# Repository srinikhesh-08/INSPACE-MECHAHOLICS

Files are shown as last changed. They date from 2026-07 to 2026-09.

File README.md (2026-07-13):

# INSPACE-MECHAHOLICS
## This is where all the hardware and software documentation for the competition will be saved

## MECHANICAL SUBSYSTEM

The Mechanical Subsystem provides the structural framework, component integration, and recovery system for the CanSat. The design follows the CAN7USAT dimensional constraints (15 cm × 40 cm) while maintaining low mass and high structural integrity during launch, deployment, descent, and landing.

The structure consists of a lightweight PETG outer casing, a six-pillar aluminium frame, and internal mounting plates for electronics, batteries, and sensors. The six-pillar configuration was selected over conventional three- and four-pillar designs due to its improved stiffness, vibration resistance, and torsional rigidity.

Recovery is achieved using a dual-stage parachute system. A drogue parachute is deployed at apogee to stabilize the vehicle, followed by the main parachute at approximately 600 m AGL to achieve a controlled landing. Deployment is servo-actuated using a spring-loaded release mechanism. A commercial off-the-shelf (COTS) altimeter provides redundant deployment capability in the event of primary sensor failure.

## ELECTRICAL POWER SYSTEM

The Electrical Power Subsystem (EPS) supplies regulated power to all avionics while ensuring reliable operation throughout the mission.

The system uses a 2S1P Samsung INR18650-30Q Li-ion battery pack (7.4 V, 3000 mAh), selected for its high current capability, competition compliance, and excellent energy density. Power is regulated through an MP1584 buck converter (7.4 V → 5 V) followed by a TPS73733 low-noise LDO regulator (5 V → 3.3 V), providing dedicated rails for digital logic and sensors.

Protection features include reverse-polarity protection, transient voltage suppression (TVS), fuse protection, battery voltage monitoring, and an externally accessible master power switch.

The average system power consumption is approximately 2.5 W, providing over 7 hours of safe operating time, significantly exceeding the competition's two-hour minimum requirement.

## SENSOR SUBSYSTEM
The Sensor Subsystem collects all mission-critical flight data required for navigation, telemetry, recovery, and post-flight analysis.

The primary altitude and temperature sensor is the BMP581, providing high-resolution pressure measurements and integrated temperature sensing. Vehicle orientation is determined using the BNO086 intelligent IMU, which performs onboard sensor fusion to provide stable quaternion-based attitude estimation while minimizing processor load.

Position and velocity are obtained using the NEO-M9N multi-constellation GNSS receiver, supporting GPS, GLONASS, Galileo, and BeiDou.

Sensor data is transmitted to the ground station through the SX1276 LoRa radio while simultaneously being stored locally on a microSD card for redundancy.

## COMMUNICATION AND DATA HANDLING

The Communication and Data Handling (CDH) subsystem manages onboard data acquisition, storage, telemetry transmission, and communication between all flight hardware.

The STM32F405 flight controller serves as the central processor, collecting data from sensors through I²C, SPI, and UART interfaces. Flight telemetry is transmitted using the SX1276 LoRa radio while identical datasets are simultaneously logged to onboard microSD storage to prevent data loss.

The subsystem maintains synchronized sensor acquisition, packet formation, telemetry scheduling, and storage throughout all flight phases. The communication architecture supports continuous monitoring of system health, mission parameters, and recovery status.

## FLIGHT SOFTWARE

The Flight Software (FSW) controls all mission operations through a finite state machine (FSM) running on FreeRTOS.

Mission execution progresses through seven primary states: Boot, Test Mode, Launch Pad, Ascent, Primary Descent, Secondary Descent, and Impact. Each state activates specific sensing, logging, telemetry, and recovery tasks appropriate for that phase of flight.

The software architecture is task-based, separating sensor acquisition, telemetry, data logging, communication, health monitoring, and state management into independent FreeRTOS tasks. This modular design improves reliability, simplifies debugging, and allows future subsystem expansion.

A dedicated TestAndSim framework enables complete mission simulation using synthetic sensor data, allowing firmware validation without flight hardware. Both unit testing and full mission integration testing are performed before deployment.

## GROUND CONTROL SYSTEM

The Ground Control System (GCS) provides real-time monitoring, visualization, and recording of flight telemetry received from the CanSat.

The desktop application is developed in Python using PyQt6 and PyQtGraph to display live telemetry, mission status, altitude, sensor measurements, and system health. Incoming LoRa packets are decoded, visualized, and simultaneously archived into timestamped CSV files for post-flight analysis.

The GCS also provides mission state indication, communication status, and recovery support, enabling operators to monitor the vehicle throughout the complete mission.

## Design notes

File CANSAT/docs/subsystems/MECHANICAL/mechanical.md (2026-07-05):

## Mechanical Subsystem

The Mechanical Subsystem is responsible for:

- Providing the structural framework of the CanSat
- Ensuring safe integration of all components
- Supporting the recovery system

Major Structural Components

1. Outer Casing
2. Structural Frame
3. Plates

### Structural Components
#### Outer Casing

Cylindrical structure conforming to CAN-7USAT dimensions (In our case it is 15x40 CM)
Protects internal components (electronics) from dust and moisture in air and also protects from Mechanical shocks during ascent and descent 
Design Requirements:
- Lightweight 
- Accessible 
- Ventilation 
CanSat outer casing should be light in weight so that it meets the mass budget but, should be strong enough and should have access to remove top and bottom for better integration and ventilation should be provided through vent holes so that sensors like pressure,temperatures exposed to outside air 

#### Materials for outer casing

- PETG
- PLA
- ABS
- Fiberglass
- Carbon fiber: By using 3D-printing we could go with PETG as better option because it is strong and light in weight compared to others

#### Structural frame 
    It is the skeleton of the cansat .It supports all components to maintain their position and protect from loads experienced during the launch,payload separation and landing.
    
#### Functions:
Components mounting 
Absorbs loads
Protection and alignment 

#### Frame Design

Number of Pillars: 6

A **hexapillar configuration** has been selected instead of 3-pillar or 4-pillar designs.

Reasons for Selection

- Higher structural strength
- Better vibration resistance
- Greater torsional rigidity

#### Materials

- 3D-printed PETG circular plates
- Aluminum pillars

Estimated Mass

- Structural frame mass: **200–250 g**

---

###  Structural Components

#### Plates

Plates serve as mounting surfaces for:

- Provides mounting surfaces for PCBs,sensors,batteries.
- Increase stiffness for CanSat 
- They are Manufactured from Lightweight material either aluminum or composites

 Other things such as fasteners and connectors are stainless steel screws ,etc..
 Safe integration of components in these structures provides nominal performance of components which meets the mission requirements such as recovery, telemetry,etc..

#### Recovery System
After separation from Launcher, CanSat needs it’s own recovery system to land safely without any damages . CanSat will have two descent control systems( Primary and Secondary) 
Recovery options:                                                           
- Parachutes 
- Rotors 
- Gliders 
- Streamers 
 The best options among them  are either parachutes or rotors, glider and streamers are not preferable due to mass and volume constraints 

#### Parachutes deploying mechanism :
Parachutes and spring system are well packed and prepared for launch, Once CanSat is deployed from the rocket, flight controller detect the condition and send command to servo to rotate and latch disengages so that spring push the top part of the CanSat and parachutes will be expelled into airflow and it inflates and continues controlled descent till landing

For **primary descent control** we use drogue parachutes will 
Engage at apogee while for secondary descent control system

We use main parachutes which will engage at 600m altitude 

#### Backup descent strategy:
All the conditions will updated to MCU by altitude sensor so, in recovery it plays a vital in engaging of parachutes at desired altitudes. In case, if any anomaly in sensor part then we activate COTS altimeter which is commercial altimeter, which will monitor the altitude independently and will guide the MCU to take further actions to recover the CanSat by deploying parachutes. 

##### COTS Preference Order:                        
1. Missile Works RRC3+
2. PerfectFlite StratoLoggerCF
3. Eggtimer Quark

---

### Parachutes: 
#### Aerodynamics of Parachutes:
The drag force is dependant upon 
1) the dynamic pressure created by moving air striking the parachute canopy (and which keeps the parachute inflated)
2) the diameter of the parachute, which determines the area over which the dynamic pressure acts 
3) the drag coefficient, Cd, of the parachute.
 Dynamic pressure is a function of velocity and air density, which in turn is dependent upon altitude and temperature.

####  Descent rate of parachutes
The vertical descent rate provided by parachute in stable descent rate is give by :



Wt = total weight of body and parachute 
S = canopy reference (surface) area   
r = air density 
To get the canopy area of parachutes :
To get descent velocity around 5m/s the relation between diameter and mass is given by:  
                                                Diameter = 0.9*(mass)^½  where mass is in kg  
                                  **Since our CanSat mass is around 1kg , required diameter is around 90cm for main chutes**

####  Calculations for descent velocity 
Mass m=1kg
Parachute diameter d=0.9m
Area A=πr² =0.64m² 
Drag coefficient Cd=0.8
Air density ρ=1.225 kg/m³ 
Using:
v=√ (2mg/ρCdA)  ≈  5.6 m/s
The terminal descent velocity is subjected to change based on air density at location of launch and weather conditions 

#### Parachute Design
Types of parachutes based on the shapes:
More common shapes are flat circular, conical, bi-conical, hemispherical, ellipsoidal, cross, annular, toroidal, ringslot, ringsail and ribbon- type 
1. Parasheet or flat circular                                          
2. Elliptical or ellipsoidal
3. Cruciform or cross

The parasheet is simplest to make, it is basically a single piece of fabric cut to a circular shape. Shroud lines are sewn onto the hemmed circumference.

####  Parachute design 




According to some research papers,
Circular form parachute is considered best of these        
1. It will give stable descent rate 
2. Prevent swinging(oscillations)
3. Open reliably 
Material: Ripston Nylon           

---

### Mass Budget

#### Electrical Components
 
| Component | Model | Est. Mass (g) |
|---|---|---:|
| Flight Computer | STM32F405 Flight Controller | 15 |
| Altimeter | BMP585 Breakout Module | 20 |
| IMU | BNO086 Breakout Module | 3 |
| GNSS | NEO-M9N Module + antenna | 22 |
| Telemetry Radio | SX1276 LoRa Module | 5 |
| Camera | M5StackCAM (OV2640) | 15 |
| Data Logger | MicroSD Module + Card | 4 |
| Buck Converter | MP1584 Module | 10 |
| LDO Regulator | TPS73733 Circuit | 1 |
| Wiring & Connectors | JSTs, headers, cables | 30 |
| PCB (custom avionics board) | Main electronics board | 30 |
| **Total (Electrical)** | | **155** |
 
#### Mechanical Components
 
| Component | Est. Mass (g) |
|---|---:|
| 2× Samsung INR18650-30Q | 100 |
| Primary Parachute | 25 |
| Secondary Parachute | 15 |
| Servo Mechanism | 30 |
| CanSat Structure (frame, fasteners, mounts) | 300 |
| Recovery Buzzer | 10 |
| Status LEDs | 2 |
| **Total (Mechanical)** | **482** |
 
#### Total Mass Budget
 
```
Total Mass = Electrical (155 g) + Mechanical (482 g) = 637 g
```

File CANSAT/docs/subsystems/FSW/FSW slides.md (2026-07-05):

# FSW Overview

- The finite state machine contains the above states:
    - BOOT
        - Hardware &software initialisation.Sensor buses, SDcard mount, previous state recovery, health diagnostics.
    - TEST_MODE
        - Live sensor validation, telemetry demo packets, SD write test, GCS link verification before launch.
    - LAUNCH_PAD
        - Pre-launch idle. 1 Hz telemetry begins. Gyro, baro & accel calibration on command. Launch detection armed.
    - ASCENT
        - All telemetry streaming.Continuous altitude, IMU, GNSS, voltage logging. Apogee detection via altitude trend.
    - PRIMARY_DESCENT
        - Post-ejection. Primary parachute deployed. Passive stabilisation. Descent rate target <20 m/s.
    - SECONDARY_DESCENT
        - Activated at 600 ± 10 m AGL. Secondary mechanism deployed.Gyroscopic stabilisation active. Target 1–3 m/s.
    - IMPACT
        - Low altitude + IMU deceleration spike. Audio beacon on. Final telemetry sent. SD card finalised.

- The FSW was divided into the following modules by functionality:
   
                          +------------------------------------------------------+
                          |                Communication Layer                   |
                          | GCS uplink/downlink • Packet serialization • Commands|
                          +--------------------------+---------------------------+
                                                     |
                                                     v
                          +------------------------------------------------------+
                          |                     FSW Core                         |
                          | State Machine • Watchdog • Task Scheduler • Commands |
                          +--------------------------+---------------------------+
                                                     |
                                                     v
                          +------------------------------------------------------+
                          |                    Data Layer                        |
                          | Sensor Fusion • Complementary Filter • AbstractState |
                          +--------------------------+---------------------------+
                                                     |
                           +-------------------------+-------------------------+
                           |                                                   |
                           v                                                   v
          +--------------------------------------+      +--------------------------------------+
          |      Hardware Controller Layer       |      |         TestAndSim Suite            |
          | IMU • Barometer • GNSS • LoRa • SD   |      | Drop-in Hardware Replacement        |
          | Hardware Drivers & Interfaces        |      | Simulated Sensors & Testing         |
          +--------------------------------------+      +--------------------------------------+

                        +----------------------------------------------+
                        |           Config Module (config.h)           |
                        | Shared configuration used by all layers      |
                        +----------------------------------------------+
```

---

- FSW TASKS (Scheduled by FreeRTOS)
    - TaskIMU
    - TaskBaro
    - TaskGNSS
    - TaskDataLayer
    - TaskFSM
    - TaskTelemetry
    - TaskCommRx
    - TaskSDWrite
    - TaskHealthMonitor
    - TaskRecoveryBeacon
- Platform
    - MCU: Arduino Nano 33 BLE Sense Rev2
    - ARM Cortex-M4F @ 64 MHz · C++ / PlatformIO + VSCode
    - Radio: XBee PRO S3B 900 MHz
    - NETID/PANID = 3165 · 1 Hz telemetry downlink
    - Storage: SD card + processor flash memory
    - State and telemetry persisted across resets
    - RTC: DS3231 mini
    - Maintains mission time through power loss

---

# Task Sampling Rates Across FSM States

```text
+-------------------+--------------------+-------+------+-------------+--------+------------------+--------------------+----------+
| Task              | Module             | BOOT  | TEST | LAUNCH_PAD  | ASCENT| PRIMARY_DESCENT | SECONDARY_DESCENT | IMPACT   |
+-------------------+--------------------+-------+------+-------------+--------+------------------+--------------------+----------+
| TaskIMU           | HardwareController | 10 Hz |10 Hz | 10 Hz       |100 Hz | 50 Hz           |100 Hz             |10 Hz     |
| TaskBaro          | HardwareController |  5 Hz | 5 Hz |  5 Hz       |20 Hz  | 10 Hz           |20 Hz              | 2 Hz     |
| TaskGNSS          | HardwareController |  1 Hz | 1 Hz |  5 Hz       | 5 Hz  |  5 Hz           | 5 Hz              | 1 Hz     |
| TaskDataLayer     | DataLayer          |  5 Hz | 5 Hz |  5 Hz       |20 Hz  | 10 Hz           |20 Hz              | 2 Hz     |
+-------------------+--------------------+-------+------+-------------+--------+------------------+--------------------+----------+
| TaskFSM           | FSWCore            | 10 Hz |10 Hz | 10 Hz       |10 Hz  | 10 Hz           |10 Hz              |10 Hz     |
| TaskHealthMonitor | FSWCore            |  1 Hz | 1 Hz |  1 Hz       | 1 Hz  |  1 Hz           | 1 Hz              | 1 Hz     |
+-------------------+--------------------+-------+------+-------------+--------+------------------+--------------------+----------+
| TaskTelemetry     | CommLayer          | OFF   | OFF  | 1 Hz*       |1 Hz   | 1 Hz            |1 Hz               |Final TX  |
| TaskCommRx        | CommLayer          | OFF   | OFF  | Interrupt   |Interrupt | Interrupt     |Interrupt          |OFF       |
+-------------------+--------------------+-------+------+-------------+--------+------------------+--------------------+----------+
| TaskSDWrite       | HardwareController | 1 Hz  |1 Hz  | 1 Hz        |1 Hz   | 1 Hz            |1 Hz               |Finalize  |
| TaskComm4G        | HardwareController |Dormant|Dormant| Dormant    |Dormant| Dormant         |Dormant            |Once      |
+-------------------+--------------------+-------+------+-------------+--------+------------------+--------------------+----------+

Notes:
* TaskTelemetry starts after CMD_START_TELEMETRY (expected during LAUNCH_PAD).
* TaskFSM and TaskHealthMonitor maintain a constant execution rate.
* Periodic task rates are updated by the FSW Core on state transitions.
* TaskCommRx is interrupt-driven (SX1278 RX ISR), not periodically scheduled.
```

---

# Payload FSW State Diagram (1/2)

## Payload FSW State Machine

```text
                               +--------------------------------------------------+
                               |                     BOOT                         |
                               | Init sensors • Mount SD • load previous state    |
                               | Health diagnostics                               |
                               +------------------------+-------------------------+
                                                        |
                                                        | All subsystems initialized
                                                        v
                               +--------------------------------------------------+
                               |                  TEST_MODE                       |
                               | Live sensor check • Telemetry demo               |
                               | SD test • GCS link verification                  |
                               +------------------------+-------------------------+
                                                        |
                                                        | CMD_ENTER_LAUNCHPAD
                                                        v
                               +--------------------------------------------------+
                               |                 LAUNCH_PAD                       |
                               | 1 Hz telemetry • Calibration commands            |
                               | Launch detection armed                           |
                               +------------------------+-------------------------+
                                                        |
                                                        | Acceleration > Threshold
                                                        | AND Altitude Increasing
                                                        v
                               +--------------------------------------------------+
                               |                   ASCENT                         |
                               | Full telemetry • IMU • GNSS • Voltage Logging    |
                               | Apogee detection                                 |
                               +------------------------+-------------------------+
                                                        |
                                                        | Sustained Negative
                                                        | Vertical Velocity
                                                        v
                               +--------------------------------------------------+
                               |              PRIMARY_DESCENT                     |
                               | Primary parachute deployed                       |
                               | Passive stabilization (<20 m/s)                  |
                               +------------------------+-------------------------+
                                                        |
                                                        | Altitude ≤ 600 ±10 m AGL
                                                        v
                               +--------------------------------------------------+
                               |             SECONDARY_DESCENT                    |
                               | Secondary mechanism deployed                     |
                               | Gyro stabilization active (1–3 m/s)              |
                               +------------------------+-------------------------+
                                                        |
                                                        | Near Ground +
                                                        | IMU Deceleration
                                                        v
                               +--------------------------------------------------+
                               |                   IMPACT                         |
                               | Audio Beacon ON • Final Telemetry                |
                               | SD Finalized • 4G GPS post                       |
                               +--------------------------------------------------+
```
- Onboard sensor suite
    - BMP586 — pressure / altitude / temperature (I²C/SPI)
    - NEO-M9N — GNSS position, altitude, UTC (UART/I²C/SPI)
    - MPU6050 — acceleration, gyroscope (I²C)
    - BNO085 — orientation, magnetometer (UART/I²C/SPI)
    - M5Stack Unit Cam- OV2640 (UART/WiFi)
    - Voltage monitor — system power health (ADC)

---

# Simulation Mode Software

- TestAndSim suite - overview
    - A compile-time swappable module (activated via config.h flag) that replaces the Hardware Controller Layer with procedurally generated sensor data. All upper layers i.e FSW Core, Data Layer and CommLayer; execute identically to flight firmware. LoRa is replaced by a loopback stub for packet inspection without radio hardware. The actual data generated is dependent on the current preset scenarios of the mission we will create, and will be saved as a collection of `scenarios` such as Nominal Flight, Apogee Edge Case, Launch Edge case and others.
- SimDriver_t controller struct
    - Owns: simulated sensor readings per channel, active scenario ID, simulation tick counter, FaultFlags_e for fault injection. Tick rate matches the highest active sensor acquisition rate to exercise full FreeRTOS load.
- Noise model
    - Per-channel noise consistent with published sensor datasheets. Fixed seed for deterministic regression runs; randomised seed for stress testing. Both modes selectable via SimDriver_t config field.

---

# Test Methodology

- The TestAndSim suite also will contain an extensive testing suite that uses both white-box and black-box testing to ensure the robustness of the software.
    - Two-level testing: unit tests (white-box) + full pipeline tests (integration, black-box) via TestAndSim; hardware testing covered separately
    - White-box: checks individual functions (FSM logic, sensor fusion, packet formatting, SD card handling) in isolation, including edge cases
    - Black-box: runs full simulated flight scenarios and checks telemetry output and state transitions against expected behavior
    - Some checks: correct state sequencing, packet counter continuity, threshold/boundary behavior, fault handling without system stalls, recovery after reset.
    - All thresholds are pulled from a central config file, so tests auto-update when values are tuned
    - Any failed test blocks are caught during development so issues are caught early, before they compound.

---

# Software Development Plan(1/2)

- Prototyping & prototyping environments
    - Development host (unit testing): White-box unit tests run on the development PC without FreeRTOS or physical hardware. Enables rapid iteration during early firmware development.
    - TestAndSim environment (integration): Full FSW pipeline on STM32 with TestAndSim replacing Hardware Controller Layer. LoRa replaced by loopback stub.
    - Proto hardware bench: Assembled proto unit with all sensors soldered and bus-connected. Sensor bring-up per sensor type
- Test Methodology
    - All tests versioned alongside firmware source. Results must be stable across multiple runs with differing noise seeds
    - Sensors are tested independently and are then integrated with FSW

    ```text
- Software subsystem development sequence

   ## Software Subsystem Development Sequence

```text
+------------------------+
| Phase 1                |
| Config & Types         |
+------------------------+
| • config.h             |
| • types.h              |
| • Thresholds           |
+------------------------+
            │
            ▼
+------------------------+
| Phase 2                |
| Hardware Controller    |
| Layer                  |
+------------------------+
| • Sensor Drivers       |
| • LoRa Tx/Rx           |
| • SD Submodule         |
+------------------------+
            │
            ▼
+------------------------+
| Phase 3                |
| Data Layer             |
+------------------------+
| • Complementary Filter |
| • Sensor Fusion        |
| • AbstractState        |
+------------------------+
            │
            ▼
+------------------------+
| Phase 4                |
| FSW Core & FSM         |
+------------------------+
| • 7-State FSM          |
| • Watchdog             |
| • State Persistence    |
+------------------------+
            │
            ▼
+------------------------+
| Phase 5                |
| Communication &        |
| Storage                |
+------------------------+
| • Binary Telemetry     |
| • Command Dispatch     |
| • SD Write Logic       |
+------------------------+
            │
            ▼
+------------------------+
| Phase 6                |
| TestAndSim &           |
| Integration            |
+------------------------+
| • SimDriver_t          |
| • Mission Scenarios    |
| • Full Pipeline Tests  |
+------------------------+
```
    ```

- Key development dependencies & milestones
    - Phase 1 (config.h / types.h) is the single source of truth and must be locked before Phase 5 binary serialisation
    - Phase 2 sensor drivers are independently testable on bench; bring up one sensor per session
    - Phase 3 complementary filter validated against synthetic inputs (unit test) before integrating with real sensors
    -  Phase 4 FSM gate: all 7 states must traverse correctly in TestAndSim nominal scenario before Phase 6 begins
    -  Phase 6 regression baseline (nominal flight scenario) becomes mandatory CI gate — failure blocks further testing Hardware proto validation (drop test, LoRa range, watchdog timeout) run in parallel with Phase 6 integration

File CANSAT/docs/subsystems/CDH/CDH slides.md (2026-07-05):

## Communication and Data Handling Subsystem
### CDH SYSTEM ARCHITECTURE

### Architecture Overview
The STM32F405 is the sole flight computer. All sensors, peripherals, and storage are subordinate devices. It manages sensor acquisition, calibration, FSM execution, packet formation, LoRa control, and microSD logging.

### Dual-Path Data Flow

### Primary Telemetry Path:
```
Sensors → STM32F405 → Packet Formation
→ SX1276 LoRa → Ground Control Station 
```

### Parallel Local Storage Path:
```
Sensors → STM32F405 → FAT32 microSD
```
Both paths operate concurrently. Data is preserved even if the LoRa link fails.

### M5Stack Camera (OV2640)
Connects via UART. Stores images locally only — does not transmit over LoRa. Operates at 2.4 GHz, providing RF isolation from the 868 MHz link.

### Peripheral Interface Assignments


### Communication Protocol- SX1276 LoRa

### LoRa Configuration Parameters
| **LoRa Configuration Parameters** |
|-----------------|
| Operating Band: 865–867 MHz (868 MHz nominal) |
| Bandwidth: 125 kHz |
| Spreading Factor: SF7 |
| Coding Rate: 4/5 |
| TX Power: 17 dBm |
| Preamble: 8 Symbols, Sync Word: 0x12 (Private Network) |
| CRC: Enabled, Mode: Half-duplex, Rate: 1 Hz |

### Design Rationale

SF7 at 125 kHz prioritises throughput and reduced air time. Link budget analysis confirms 56 dB margin at 1 km LOS — substantially exceeding operational requirements.

The private sync word 0x12 isolates the CanSat link from other LoRa devices at shared launch events.

Hardware CRC provides physical-layer error detection. This is the first of four independent integrity layers in the system.

Half-duplex uses dedicated TX/RX windows. The CanSat enters LAUNCH_PAD on power-up and awaits CMD_START_TELEMETRY before activating the downlink, preventing premature RF emissions.

### Telemetry Packet Content (~73 bytes, fixed layout)
- Mission Time, Packet Count, Flight State
- Altitude, Pressure, Temperature
- Battery Voltage, System Health Flags
- GPS: latitude, longitude, altitude, satellite count
- IMU: acceleration X/Y/Z, angular velocity X/Y/Z, orientation
Fixed-length binary packed C structure — deterministic GCS parsing.

### Communication Link Budget Analysis

```
**Step 1 — Free-Space Path Loss**
Signal attenuation due to geometric spreading over the link distance (unobstructed LOS):
FSPL(dB) = 20·log₁₀(d) + 20·log₁₀(f) + 32.44
d = distance in km, f = frequency in MHz
FSPL = 20·log(1) + 20·log(867) + 32.44
= 0 + 58.76 + 32.44 ≈ 91 dB

**Step 2 — Received Power**
Pr = Pt + Gt + Gr − FSPL
Pt = 17 dBm (TX power)
Gt = 2 dBi (CanSat monopole)
Gr = 5 dBi (GCS collinear)
Pr = 17 + 2 + 5 − 91 = −67 dBm

**Step 3 — Link Margin**
LM = Pr − Sensitivity
= −67 − (−123) = 56 dB
```

#### What Does 56 dB Mean?
The received signal is 56 dB above the SX1276 demodulation floor. Every 6 dB doubles tolerable degradation:

- Antenna orientation loss (monopole perpendicular to link): 10–15 dB — fully covered
- Typical multipath fading: 10–20 dB — fully covered
- Launch-site interference from adjacent LoRa teams: covered
- Conservative values used (2 dBi / 5 dBi) — actual margin likely higher

SF7 confirmed appropriate for 1 km LOS profile. Adjustable to higher SF if ground testing reveals unexpected degradation.

| **Summary** |
|-----------------|
| TX: 17 dBm |
| CanSat: 2 dBi |
| GCS: 5 dBi |
| FSPL @ 1 km |
| 867 MHz ≈ 91 dB |
| Pr = −67 dBm |
| Sensitivity: −123 dBm, Link Margin: 56 dB — Robust |

---

### Antenna System Design

#### CanSat — Quarter-Wave Monopole
Omnidirectional azimuthal radiation pattern selected because CanSat orientation cannot be controlled during descent.

##### Length Calculation:
L = c / (4 × f)
c = 3 × 10⁸ m/s, f = 867 MHz
L = (3×10⁸) / (4×867×10⁶) ≈ 8.6 cm
Copper conductor selected for high conductivity, low mass, and ease of fabrication. PCB ground plane serves as counterpoise.

#### CanSat Antenna Specifications
Type: Quarter-wave whip monopole
Material: Copper wire conductor
Frequency: 865–867 MHz
Gain: 2–3 dBi
Polarisation: Vertical
Pattern: Omnidirectional (azimuthal)
Length: ≈ 8.6 cm
Mounting: Above PCB ground plane (counterpoise)

#### GCS Antenna
Fiberglass-enclosed collinear, selected for increased gain while maintaining omnidirectional coverage without active tracking. Compensates for the CanSat's constrained installation and contributes directly to the 56 dB link margin.

GCS Antenna Specifications
1. Type: Fiberglass omnidirectional collinear
2. Material: Radiating elements enclosed in fiberglass radome
3. Frequency: 865–867 MHz
4. Gain: 5–8 dBi
5. Polarisation: Vertical
6. Pattern: Omnidirectional
7. Mounting: Fixed tripod or mast
8. Tracking: Not required

#### Polarisation Matching
Both antennas use vertical polarisation. Matched polarisation minimises polarisation loss — a mismatch would contribute 3–6 dB of avoidable attenuation.

##### Why No Tracking?
The 56 dB margin provides sufficient tolerance for signal variation caused by CanSat rotation over the 1 km mission profile. Active tracking hardware adds mass and complexity without a measurable benefit given the available margin.

---

### Telecommand Architecture — Uplink Design
| 6-Byte Command Packet |
| Byte 0: Sync Byte — 0xAA |
| Bytes 1–2: Team Number (uint16_t) |
| Byte 3: Opcode — command identifier |
| Byte 4: Parameter — command argument |
| Byte 5: XOR Checksum over Bytes 0–4 |

#### ACK / NACK Protocol
- Valid command (all layers passed + FSM state compatible) → ACK
- Invalid/incompatible → NACK
- Distinguishes a rejected command from a lost packet, providing diagnostic information that a timeout-only approach cannot supply

#### Supported Commands
| Opcode | Command |
|---|---|
| 0x01 | CMD_START_TELEMETRY |
| 0x02 | CMD_STOP_TELEMETRY |
| 0x03 | CMD_CALIBRATE_BARO |
| 0x04 | CMD_CALIBRATE_GYRO |
| 0x05 | CMD_CALIBRATE_ACCEL |
| 0x06 | CMD_ENTER_TEST |
| 0x07 | CMD_ENTER_LAUNCHPAD |
| 0x08 | CMD_SWITCH_CHANNEL |

#### 3-Layer Validation

#### Layer 1 — Sync Byte (0xAA)

- Rapid pre-filter
- Discards malformed packets, truncated transmissions, and frames from unrelated LoRa devices
- First position minimizes rejection cost

#### Layer 2 — Team Number

- Multiple teams may operate LoRa ground stations on the same frequency
- The uint16_t team identifier acts as a logical address layer
- Prevents cross-team command interference

#### Layer 3 — XOR Checksum

- XOR computed over Bytes 0–4
- Receiver independently recomputes and compares checksum
- Any bit corruption causes mismatch and packet rejection
- Provides a second integrity check above LoRa hardware CRC

The three layers defend against: noise-induced bit errors, cross-team interference, and corrupted packet execution. No single layer is sufficient in isolation.

---

### Data Acquisition System

#### BMP585 — Barometric Pressure Sensor

Provides atmospheric pressure and temperature measurements. Altitude is derived using the barometric formula. Serves as the primary sensor for flight state detection and apogee identification.

| Parameter | Value |
|---|---|
| Interface | I²C on PB6/PB7 |
| Address | Unique device address |
| Power | 0.000016 W continuous |

#### BNO086 — Inertial Measurement Unit

Provides 3-axis acceleration, angular velocity, and fused orientation (roll, pitch, yaw). The onboard fusion processor reduces STM32F405 computational load.

| Parameter | Value |
|---|---|
| Interface | I²C on PB6/PB7 |
| Bus Sharing | Shares bus with BMP585 |
| Power | 0.059 W continuous |

#### NEO-M9N — GNSS Receiver

Provides GPS positioning (latitude, longitude, altitude) and UTC time. UTC serves as the mission elapsed time reference independent of the onboard crystal oscillator.

| Parameter | Value |
|---|---|
| Interface | UART1 on PA9 (TX) / PA10 (RX) |
| Power | 0.224 W continuous |

#### Adaptive Sampling Strategy

| Device | Flight Phase | Sampling Rate | Purpose |
|---|---|---|---|
| BMP585 | Launch Pad | 5 Hz | Baseline monitoring |
| BMP585 | Ascent | 20 Hz | Apogee detection |
| BNO086 | Initialization | 10 Hz | Calibration and baseline establishment |
| BNO086 | Ascent | 100 Hz | Capture deployment and attitude transients |
| NEO-M9N | All Phases | 1–5 Hz | Position tracking |
| Telemetry Downlink | All Phases | 1 Hz | LoRa transmission rate |

The 100 Hz IMU sampling rate during ascent is a key design decision, ensuring high-frequency dynamic events are captured without aliasing.

---

### Flight State Machine — 7-State Mission FSM

#### FSM State Transitions

| From State | To State | Transition Condition |
|---|---|---|
| BOOT | TEST_MODE | Initialization sequence completed |
| TEST_MODE | LAUNCH_PAD | All subsystem health checks passed |
| LAUNCH_PAD | ASCENT | Sustained acceleration above threshold and positive altitude rate |
| ASCENT | PRIMARY_DESCENT | Apogee detected and sustained negative vertical velocity |
| PRIMARY_DESCENT | SECONDARY_DESCENT | Altitude below 600 ± 10 m AGL |
| SECONDARY_DESCENT | IMPACT | Near-ground altitude and IMU deceleration spike |
| IMPACT | Terminal State | Recovery mode and data preservation active |

#### Configurable Threshold Philosophy

Only the 600 ± 10 m AGL threshold is finalized.

Reasons for deferring other thresholds:

- Thresholds depend on aerodynamic and structural characteristics of the final assembly
- Reliable prediction is not possible without empirical testing
- Premature commitment risks invalid assumptions due to hardware modifications or parachute behavior
- Configurable parameters allow updates without firmware recompilation

#### Qualification Process

1. 6-DOF simulation to establish initial estimates
2. Bench testing of individual sensor responses
3. Integrated ground testing of the complete FSM
4. Flight validation and refinement
5. Final values documented during CDR

#### Boot Sequence

```text
Power
→ Sensor Initialization
→ Bus Initialization (SPI1, SPI2, I²C, UART1)
→ SD Mount
→ Telemetry Initialization
→ Health Check
→ State Restore
→ BOOT
→ TEST_MODE
→ LAUNCH_PAD
→ Await CMD_START_TELEMETRY
```
---

### CDH Subsystem Power Budget
P = V × I
| Symbol | Description |
| --- | --- |
| P | Power (W) |
| V | Voltage (V) |
| I | Current (A) |

Example: 
V = 3.3 V
I = 110 mA = 0.110 A
P = 3.3 × 0.110
P = 0.363 W
All subsystem power values are derived using the same method and datasheet specifications.

#### SX1276 Duty Cycle Analysis
- Half-duplex operation at 1 Hz
- TX occupies approximately 20% of each cycle
- Idle occupies approximately 80% of each cycle
- 
TX Average   = 0.396 W × 0.20 = 0.079 W
Idle Average = 0.033 W × 0.80 = 0.026 W

Weighted Average ≈ 0.105 W

##### M5Stack Camera

At 0.80 W, the M5Stack Camera is the largest single CDH power consumer. Its intermittent operation during descent limits total energy consumption over the mission duration.

#### CDH POWER CONSUMPTION TABLE
| Component | Voltage | Current  | Power | Duty Cycle |
| --- | --- | --- | --- | --- |
| STM32F405 | 3.3 V | 110 mA | 0.363 W | Continuous |
| BMP585 | 3.3 V | 0.005 mA | 0.000016 W | Continuous |
| BNO086 | 3.3 V | 17.9 mA  | 0.059 W | Continuous |
| NEO-M9N | 3.3 V | 67.9 mA  | 0.224 W | Continuous |
| SX1276 TX | 3.3 V | 120 mA | 0.396 W | 20% Duty |
| SX1276 Idle | 3.3 V | 10 mA | 0.033 W | 80% Duty |
| microSD | 3.3 V | 50 mA | 0.165 W | Continuous |
| M5Stack Camera | 5.0 V | 160 mA | 0.800 W | Intermittent |

---

### Data Processing, Integrity and Storage

##### Onboard Processing

STM32F405 performs:

1. Sensor acquisition
2. Unit conversion
3. Calibration
4. FSM execution
5. Telemetry packet assembly

- Active FSM state determines sampling rates and operational behavior.

##### Packet Formation

- Fixed-layout binary packed C structures
- Approximately 73 bytes per packet
- Deterministic GCS parsing
- No framing ambiguity

#### Data Integrity - 4 Layers

##### Layer 1 - LoRa Hardware CRC

- Physical-layer bit error detection performed by SX1276 hardware.

##### Layer 2 - Application XOR Checksum

- Computed before transmission.
- Verified upon reception.
- Invalid packets discarded before processing.

##### Layer 3 - Sequential Packet Counter

- Incremented for every packet.
- Enables gap detection and continuity monitoring.

##### Layer 4 - Telecommand Validation

- Sync Byte validation.
- Team ID validation.
- XOR checksum validation.
- ACK/NACK closes the command loop.

#### Storage Architecture

- FAT32 microSD connected via SPI1 (PA5-PA7, PA4 CS).

Stored data includes:

1. Telemetry data (sensor readings and computed values)
2. Mission state transitions (FSM state logs)
3. Recovery information (GPS landing coordinates)

#### Mission Continuity After Reset

The following values are continuously persisted to microSD:

1. Mission elapsed time
2. Packet counter
3. Current flight state

Upon reset, these values are restored before mission execution resumes.

Benefits:

1. Packet numbering continuity
2. Mission time consistency
3. State preservation

#### Mission Timing

- NEO-M9N GPS UTC time provides an absolute mission time reference independent of the onboard crystal oscillator.
- Eliminates long-term clock drift errors.

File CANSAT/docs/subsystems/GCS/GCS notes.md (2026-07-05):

# CanSat - CDH

## Contents

- GCS Hardware and Software Architecture
- GCS Mission Status Panel and Command Interface
- GCS Real-Time Displays and Attitude Visualisation
- GCS Logging, Recovery Interface and Field Deployment
- Telemetry and Telecommand Packet Structure
- Communication Validation Architecture — 4-Layer Defence
- Boot Sequence — 9-Step Initialisation Workflow (Finalised)
- Mission Continuity and Reset Recovery
- System Design Justification — Consolidated Engineering Rationale
- Preliminary Link Budget Analysis
- Mission Timing Architecture — GNSS-Synchronised
- Transmission Loss Mitigation and Backup RF Capability

---
# GCS Hardware and Software Architecture

- GCS Hardware Configuration

    - Laptop Computer:                      Primary processing, display, and logging platform
    - SX1276-compatible LoRa receiver:      RF reception and telecommand uplink transmission
    - USB-to-UART interface:                Bridge between LoRa receiver and laptop software
    - Fiberglass collinear antenna:         865–867 MHz, 5–8 dBi gain, vertical polarisation, tripod-mounted
    - Portable field power source:          Independent operation — no mains electricity required

    - Configured: 865–867 MHz | SF7 | BW 125 kHz | CR 4/5 | Sync 0x12

- GCS Software Stack

    - Python — Core application language:           Cross-platform; serial I/O, data processing, GUI integration
    - PyQt6 — GUI framework:                        Event-driven; multi-panel layouts, custom widgets
    - PyQtGraph — Real-time plotting:               OpenGL-accelerated; updates at 1 Hz telemetry rate
    - Pandas — Data processing:                     CSV logging; time-series operations; structured data
    - NumPy — Numerical computation:                Vertical velocity derivation; vectorised operations

---
# GCS Mission Status Panel and Command Interface

- Mission Status Panel

    - Persistent panel updating at 1 Hz with each incoming packet:

    - Mission Elapsed Time — from GPS UTC in telemetry
    - Packet Count — total received; gaps from sequence counter Mission State — reflects current CanSat FSM state
    - RSSI (dBm) — signal strength from LoRa receiver SNR (dB) — signal-to-noise ratio
    - Battery Voltage — real-time power health
    - Reset Count — processor resets since mission start Communication Link Status — active / lost / degraded

- Command Interface

    - XOR checksum auto-computed by GCS software — every packet structurally valid. ACK/NACK displayed per command.

    - 0x01 CMD_START_TELEMETRY — Activate downlink
    - 0x02 CMD_STOP_TELEMETRY — Suspend downlink
    - 0x03 CMD_CALIBRATE_BARO — Barometric zero
    - 0x04 CMD_CALIBRATE_GYRO — Gyro calibration
    - 0x05 CMD_CALIBRATE_ACCEL — Accel calibration
    - 0x06 CMD_ENTER_TEST — Transition to TEST_MODE
    - 0x07 CMD_ENTER_LAUNCHPAD — To LAUNCH_PAD
    - 0x08 CMD_SWITCH_CHANNEL — Switch radio channel

---
# GCS Real-Time Displays and Attitude Visualisation

- Real-Time Telemetry Display
    - Structured display by category, updating at 1 Hz:
        - Environmental
            - Altitude (m AGL), Pressure (hPa), Temperature (°C)
        - IMU
            - Acceleration X, Y, Z (m/s²) Angular velocity X, Y, Z (deg/s)
        - GPS
            - Latitude, Longitude (decimal degrees) GPS Altitude (m), Satellite count
        - Power and Communication
            - Battery voltage (V)
            - RSSI (dBm), SNR (dB), Packet count, Link status

- Attitude Visualisation Panel
    - Dedicated panel: Artificial horizon, roll, pitch, heading — driven by BNO086 orientation data. Continuous visual monitoring without manual        interpretation of raw angular rates.

- Real-Time Plots (PyQtGraph, 1 Hz)
    - Flight Data
        - Altitude vs. Time 
        - Pressure vs. Time
        - Temperature vs. Time
        - Vertical Velocity vs. Time (derived)
    - IMU
        - Acceleration X, Y, Z vs. Time 
        - Angular Velocity X, Y, Z vs. Time
    - Orientation
        - Roll, Pitch, Yaw vs. Time
    - GPS and Power
        - Latitude, Longitude, GPS Altitude, Satellite Count 
        - Battery Voltage vs. Time

---
# GCS Logging, Recovery Interface and Field Deployment

- Data Logging
    - Timestamped CSV files on local storage. Logged per packet:
        - Mission Time (ms since launch epoch) 
        - Packet Number
        - All sensor fields: altitude, pressure, temp, accel X/Y/Z, ang-vel X/Y/Z, roll, pitch, yaw
        - GPS: lat, lon, altitude, satellite count 
        - Mission State (FSM identifier)
        - RSSI (dBm), SNR (dB)

- GCS Mission Continuity
    - On GCS software restart, the application recovers mission time, packet count, and flight state from the last CSV log before resuming — maintaining GCS coherence after a laptop interruption.

- Recovery Interface
    - After CanSat transitions to IMPACT state:
        - Launch location — fixed reference 
        - Current GPS position — last received 
        - Landing position — last valid fix
        - Recovery guidance — direction and distance

- Field Deployment
    - Designed for rapid deployment by a small team: 
        - Position laptop at operations area 
        - Connect LoRa receiver via USB-to-UART 
        - Erect tripod, mount collinear antenna 
        - Connect portable power source
        - Launch GCS software; verify receiver configuration 
        - Issue CMD_START_TELEMETRY once CanSat powered

- Design Justification
    - Python/PyQt6/PyQtGraph: cross-platform, mature libraries, single application integrating serial handling, processing, and visualisation.
    - Automatic XOR checksum eliminates operator errors in packet construction. ACK/NACK provides unambiguous command confirmation.
    - 5–8 dBi collinear antenna is the primary ground-side contributor to the 56 dB link margin from the CDH link budget.

---
# Telemetry and Telecommand Packet Structure

- Telemetry Packet — 75 Bytes (Finalised)
    - 0 team_number uint16_t 2B
    - 2 mission_time uint32_t 4B 
    - 6 packet_count uint16_t 2B 
    - 8 altitude float 4B
    - 12 pressure float 4B 
    - 16 temperature float 4B 
    - 20 voltage	float 4B
    - 24 gnss_time  uint32_t 4B 
    - 28 latitude	float 4B
    - 32 longitude  float 4B 
    - 36 gnss_altitude float 4B
    - 40 gnss_sats  uint8_t 1B
    - 41 accel_x/y/z float x3 12B 
    - 53 roll, pitch float x2 8B
    - 61 gyro_x/y/z  float x3 12B
    - 73 flight_state uint8_t 1B
    - 74 checksum	uint8_t 1B
    
    - Earlier revisions referenced a 73-byte packet; the structure above (75 bytes) is the finalised PDR definition and supersedes that figure throughout this report.

- Telecommand Packet — 6 Bytes
    - Byte 0: Sync Byte = 0xAA
    - Bytes 1–2: Team Number (uint16_t)
    - Byte 3: Opcode
    - Byte 4: Parameter
    - Byte 5: XOR Checksum (Bytes 0–4)

- Key Design Points

    - Packed struct — no compiler padding; identical layout in firmware and GCS parser
    - Little-endian byte order (STM32F405 native) 
    - packet_count (offset 6) enables GCS gap detection
    - checksum (offset 74) is the application-layer XOR — Layer 4 of validation architecture
    - flight_state (offset 73) directly drives GCS Mission State display
    - 6-byte command format minimises uplink air time while retaining sync, source ID, and integrity check

---
# Communication Validation Architecture — 4-Layer Defence

- 4-Layer Validation Pipeline
    - Layer 1 — LoRa PHY Synchronisation
        - Applied to: all received frames. Addresses: bit errors from channel noise; frame misalignment
    - Layer 2 — Team Number Filtering
        - Applied to: all received packets. Addresses: cross-team command interference at shared launch sites
    - Layer 3 — CRC Validation
        - Applied to: all received packets. Addresses: residual bit errors not caught by PHY sync
    - Layer 4 — XOR Checksum Verification
        - Applied to: telemetry + telecommand. Addresses: application-layer corruption; end-to-end integrity
    - Telecommand-Only: Sync Byte (0xAA) + FSM-State Check
        - Final gates before command execution

- Why Layered Validation?
    - Each layer addresses a distinct failure mode. No single layer is sufficient in isolation — removing any one leaves the system vulnerable to the failure mode it specifically addresses.

- Telecommand-Specific Gates
    - Telecommand packets pass through two additional checks beyond the four layers:
        - Sync byte validation — Byte 0 must equal 0xAA
        - FSM-state compatibility — command must be valid in current state
    - Only packets satisfying all applicable conditions are accepted for processing. A command failing any check returns NACK; a valid command compatible with the current FSM state returns ACK.

- Outcome
    - This architecture defends simultaneously against: random channel noise, RF interference from co-located teams, packet collisions, and accidental or malicious cross-team commands — each addressed by a different layer.

---
# Boot Sequence — 9-Step Initialisation Workflow (Finalised)

- Boot Sequence — Finalised
    - The flight software boot sequence is finalised. Each step completes successfully before the next begins; a failure is recorded in the health diagnostic log and reported to the GCS once telemetry is established.

    - 1. Power Application
        - Main power rail established; regulators stabilise supply
    - 2. STM32F405 Initialisation
        - Flight computer core, clocks, internal peripherals operational
    - 3. Sensor Initialisation
        - BMP585, BNO086, NEO-M9N out of reset; registers configured
    - 4. Communication Bus Init
        - SPI1, SPI2, I²C, UART1 initialised at configured rates
    - 5. microSD Mounting
        - FAT32 mounted on SPI1; log files opened; write access verified
    - 6. Telemetry Subsystem Init
        - SX1276 configured; TX/RX buffers initialised
    - 7. Health Diagnostics
        - All subsystem self-tests executed; faults flagged
    - 8. Previous Mission-State Recovery
        - Persisted time, packet count, FSM state read from microSD
    - 9. Transition to BOOT Completion
        - BOOT → TEST_MODE → LAUNCH_PAD; awaits CMD_START_TELEMETRY

- Boot-Time Measurement — PDR Status
    - A measured boot duration has not yet been established, as integrated hardware testing has not been completed. The sequence itself (left) is fully finalised — only the timing measurement is pending.
    - Boot-time measurement will be finalised during integrated system testing and flight qualification activities, with the measured value reported at the Critical Design Review.

- Step 8 — Previous Mission-State Recovery
    - Entry point to the reset recovery workflow detailed on the next slide. Ensures the system resumes with the correct mission time, packet counter, and FSM state after any processor reset, during initial boot or mid-mission.

- Step 9 — Transition to BOOT Completion
    - The FSM completes BOOT, transitions through TEST_MODE on successful validation, then to LAUNCH_PAD. The system remains in LAUNCH_PAD — sensors active, telemetry link established, downlink not yet transmitting — until CMD_START_TELEMETRY is received from the GCS.

---
# Mission Continuity and Reset Recovery

- Persisted Mission Variables
    - Three variables are continuously written to microSD during operation, enabling coherent recovery after an unplanned processor reset:
        - Mission Elapsed Time
            - Written each telemetry cycle — provides time continuity after reset
        - Packet Counter
            - Written each telemetry cycle — GCS never sees a counter reset to zero
        - Current FSM State
            - Written on every state transition — correct operational state resumed

- Why This Matters
    - Without persisted state, a processor reset mid-mission would restart the packet counter from zero, reset mission time to zero, and force the FSM back to BOOT — producing a telemetry record the GCS cannot reconcile with pre-reset data.
    - Persisted state ensures the post-reset stream is a continuation, not a restart.
    - The GCS distinguishes a reset event from packet loss via the Reset Count field: a reset produces a small time gap with continuity preserved, whereas packet loss produces sequence-counter gaps with no time discontinuity.

- Reset Recovery Workflow
    - 1. Read Stored State
        - Mission state log file read from microSD
    - 2. Restore Packet Counter
        - Resume from last persisted packet_count value
    - 3. Restore Mission Time
        - Resume from last persisted mission_time value
    - 4. Restore FSM State
        - Resume in the last persisted flight_state
    - 5. Resume Nominal Operation
        - Continue sensor sampling, telemetry, and logging from restored context

    - This workflow executes as Step 7 of the boot sequence and applies identically whether the reset occurs during pre-launch testing or mid-flight.

---
# System Design Justification — Consolidated Engineering Rationale

- SX1276 LoRa Transceiver
    - Long-range, low-power, high interference immunity — well-suited to shared launch sites with multiple concurrent RF systems

- SF7 Spreading Factor
    - Highest LoRa throughput; 56 dB link budget margin makes additional margin from higher SF unnecessary

- Dual-Path Architecture
    - Simultaneous LoRa telemetry + microSD logging — mission data survives any link failure; no in-flight recovery possible otherwise

- Configurable FSM Thresholds
    - Thresholds beyond the mission-specified 600 m AGL are deferred — separates tuning from firmware recompilation, enabling rapid post-test iteration

- Layered Validation Architecture
    - 4 independent layers (PHY sync, team ID, CRC, XOR) each address a distinct failure mode — no single point of validation failure

- Vertical Antenna Polarisation
    - Matched polarisation on both ends eliminates 3–6 dB of avoidable mismatch loss

- Omnidirectional Antenna Pattern
    - CanSat rotates continuously during descent — omnidirectional pattern avoids orientation-dependent signal nulls a directional antenna would introduce

- Higher-Gain GCS Antenna
    - 5–8 dBi collinear compensates for CanSat's constrained monopole and boosts link margin without CanSat-side complexity or tracking hardware

---
# Preliminary Link Budget Analysis

- Assumptions
    - TX Power (Pt) = 17 dBm
    - CanSat Antenna Gain (Gt) = 2 dBi 
    - GCS Antenna Gain (Gr) = 5 dBi
    - Link Distance (d) = 1 km | Frequency (f) = 867 MHz
    - SX1276 Sensitivity (SF7, 125 kHz BW) = −123 dBm

- Equations
    - FSPL(dB) = 20·log₁₀(d) + 20·log₁₀(f) + 32.44 Pr = Pt + Gt + Gr − FSPL
    - LM = Pr − Sensitivity

- Calculations
    - FSPL = 20·log(1) + 20·log(867) + 32.44 ≈ 91 dB 
    - Pr = 17 + 2 + 5 − 91 = −67 dBm
    - LM = −67 − (−123) = 56 dB

- Results and Interpretation
    - FSPL @ 1 km, 867 MHz ≈ 91 dB
    - Received Power (Pr) ≈ −67 dBm
    - Link Margin (LM) ≈  56 dB — ROBUST

- Significance of 56 dB Margin
    - The received signal is 56 dB above the SX1276 demodulation floor. Each 6 dB of margin doubles the tolerable signal degradation, so 56 dB represents a very large safety factor.
    - This margin accommodates:
        - Antenna orientation losses: 10–15 dB for a misaligned monopole — fully covered
        - Typical multipath fading: 10–20 dB — fully covered
        - Launch-site RF interference from co-located teams — covered
    - SF7 is confirmed appropriate for the 1 km LOS mission profile, with margin to adjust to a higher spreading factor if ground testing reveals degradation not captured by the free-space model.

---
# Mission Timing Architecture — GNSS-Synchronised

- No Dedicated RTC Module
    - The CDH subsystem does not use a dedicated external real-time clock (RTC) IC. Instead, mission timing is implemented as a GNSS-synchronised architecture.

- Time Architecture
    - GNSS UTC time (NEO-M9N) is the primary absolute time reference 
    - STM32F405 generates mission elapsed time relative to launch epoch 
    - Mission time included in every telemetry packet (offset 2)
    - Mission time persisted to microSD and restored on reset recovery 
    - Raw GNSS time (offset 24) also logged for post-flight correlation

- Why GNSS-Synchronised vs. RTC?
    - A GNSS-derived absolute reference is referenced to a global atomic time standard, eliminating the drift associated with onboard crystal oscillators over multi-hour missions — without the added component, power, and battery-backup overhead of a separate RTC IC.

- Timing Data Flow
    - NEO-M9N GNSS Receiver:            Provides UTC time — primary absolute reference
    - STM32F405 Flight Computer:        Generates mission elapsed time from launch epoch
    - Telemetry Packet (offset 2):      mission_time included in every 75-byte packet
    - microSD Persistence:              mission_time saved each cycle — reset recovery source
    - Telemetry Packet (offset 24):     Raw gnss_time also logged for post-flight correlation

- Dual recording of both GNSS time and mission elapsed time in every packet allows post-flight analysis to cross-reference onboard event timing against an independent absolute clock.

---
# Transmission Loss Mitigation and Backup RF Capability

- Dual-Path Telemetry Handling
    - Primary — Real-Time Telemetry:                SX1276 LoRa downlink to GCS at 1 Hz — live mission monitoring
    - Secondary — Onboard Data Preservation:        Simultaneous logging of the same packet to FAT32 microSD, independent of RF link status

- Key Outcome
    - Every telemetry packet generated by the flight computer is both transmitted via LoRa and logged to microSD. Because both paths execute for every packet, loss of the RF communication link does not result in loss of mission data — all mission telemetry remains available for post-flight recovery and analysis via the onboard storage subsystem.

- PDR-Stage Mitigation Approach
    - Transmission-loss mitigation at PDR stage is achieved through dual-path telemetry handling — real-time LoRa transmission combined with simultaneous onboard logging — rather than through a currently implemented secondary RF link.

- Backup RF Channel Capability
    - CMD_SWITCH_CHANNEL (Opcode 0x08)
    - Reserved capability for alternate RF channel selection — implemented and validated through the standard telecommand pipeline

- Deferred to CDR — Reasons
    - Final spectrum planning has not yet been completed Channel allocation depends on integrated RF testing
    - Current PDR focuses on the primary communication architecture

- Backup During Transmission Loss — SATISFIED
    - Via simultaneous onboard logging + mission-state persistence. Backup RF channel capability exists in command architecture; channel definitions remain a CDR item

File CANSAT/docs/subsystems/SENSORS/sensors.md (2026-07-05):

## Sensor Subsystem Overview

| Subsystem | Primary Sensor | Function |
|---|---|---|
| Altitude + Temperature | BMP581 | Provides integrated pressure and temperature readings, eliminating the need for a separate temperature module |
| Air Temperature | BMP581 (Integrated) | Measures ambient air temperature as part of barometric sensing |
| Navigation (GNSS) | NEO-M9N | Measures absolute position, velocity, and time data throughout flight |
| Tilt Orientation / IMU | BNO086 | Tracks orientation, rotation rate, and linear acceleration |
| Magnetometer | BNO086 (via fusion) | Provides Earth magnetic field direction and magnitude using onboard sensor fusion (CEVA) |
| Telemetry | LoRa SX1278 | RF communication at 433 MHz for long-range data transmission |
| Data Logging | microSD (SPI) | Onboard storage of flight data for post-mission analysis |

## Barometric Sensor Comparison

| Sensor | Weight | Pressure Accuracy | Altitude Accuracy | Communication Interface | Output Data Rate (ODR) | Power Consumption | Operating Voltage | Cost (INR) | 
|---|---|---|---|---|---|---|---|---|
| BMP180 | 5 g | ±1–4 hPa | ~0.03 hPa (~varies, 18-bit resolution) | I2C | ~1 Hz | ~650 µA | 1.8–3.6 V | ~₹50 |
| BMP280 | 3–5 g | ±1 hPa @ 25°C | ±0.12 hPa (~±1 m) | I2C, SPI | Moderate | ~714 µA | 1.71–3.6 V | ₹400–800 |
| BMP581 / BMP585 | 3–5 g | ±0.5 hPa max | ±6 Pa (~±0.5 m) | I2C, I3C, SPI | Up to 622 Hz | ~260 µA (active) | 1.71–3.6 V | ₹800–1100 |

**Critical Performance Requirements** 
• Altitude resolution: < 1 m  (required for apogee detection) 
• Sampling rate: 100–622 Hz  (fast ascent tracking) 
• Noise immunity: Critical  (high vibration environment) 
• Shock survival: Passive MEMS OK with foam/rubber damping 
• Temperature: Onboard compensation preferred for flight accuracy 

## Payload Air Temperature selection

| Role | Sensor | Justification |
|---|---|---|
| Primary Altimeter | BMP581 / BMP585 | 622 Hz ODR, ±0.5 m accuracy, FIFO buffer, onboard low-pass filtering — best-in-class performance for rocketry applications |
| Backup Altimeter | BMP280 | Proven, low-cost redundancy with sufficient accuracy for fail-safe altitude estimation |
| Temperature Sensor | BMP581 (Integrated) | Uses internal calibrated temperature sensor — reduces weight, cost, and system complexity |

## GNSS Module Comparison

| Sensor | Weight | Position Accuracy | Satellite Constellations | Communication Interface | Output Data Rate (ODR) | Power Consumption | Operating Voltage | Cost (INR) |
|---|---|---|---|---|---|---|---|---|
| NEO-6M | ~50 g | ~2.5 m | GPS only | UART | ~1 Hz (low) | Low | 2.7–3.6 V | ₹300–500 |
| NEO-M8N | ~25 g | ~0.6–0.9 m | GPS + GLONASS | UART | Moderate | Low | 3.3 V | ~₹2000 |
| NEO-M9N | Light | ~1.5 m CEP | GPS + GLONASS + Galileo + BeiDou | UART, I2C, SPI | Up to 20–30 Hz (varies by config) | ~30 µA (low-power mode) | 3.3 V | ₹2000+ |

**Sensor Justification:**
**Primary**- GPS NEO-M9N:
25 Hz, quad-constellation, anti jamming, 80 km altitude, 500 m/s 
— rated for aerospace dynamics
**Secondary Backup**- GPS NEO-M8N
High accuracy (0.9 m), proven in UAVs/drones, lower cost fallback

## IMU Sensor Comparison

| Sensor | Accel Range | Sensor Fusion | Output Data Format | Communication Interface | Gyro Range | Power Consumption | Operating Voltage | Cost (INR) |
|---|---|---|---|---|---|---|---|---|
| MPU-6050 | ±2–16 g | DMP (built-in) | Raw + DMP | I2C | ±250–2000 dps | Low | 2.3–3.4 V | ₹150–250 |
| BNO055 | ±2–16 g | Built-in fusion | Euler, Quaternion | I2C | ±250–2000 dps | Low | 2.4–16 V | ₹1300–1700 |
| BNO086 | ±2–16 g | Advanced Motion Engine | Orientation, rotation vectors | I2C, SPI | High precision | Moderate (~30 µA) | 3.3 V | ₹2000+ |

**BNO086-**
• CEVA Motion Engine: advanced onboard sensor fusion 
• Real-time orientation output with dynamic calibration 
• Handles vibration and high-motion environments better than BNO055 
• Minimizes MCU load — direct quaternion/rotation vector output 
• Designed for robotics, drones, and high-motion aerospace systems

## Final Sensor Combination

| Sensor Role | Sensor | Justification |
|---|---|---|
| Primary Orientation | BNO086 (IMU) | Sensor fusion IMU eliminates magnetometer noise issues; best practical solution for stable real-time orientation |
| Backup Magnetometer | MMC5983MA | Used only if implementing advanced external fusion; high precision (±0.5°) with up to 1000 Hz ODR |
| Temperature | BMP581 (Integrated) | Uses internal calibrated temperature sensor — no extra weight, cost, or complexity |

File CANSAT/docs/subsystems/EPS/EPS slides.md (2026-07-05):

## CANSAT COMPONENT SUMMARY
| Category | Component | Function / Role | Operating Voltage |
|---|---|---|---|
| Flight Computer | STM32F405 | Main MCU – telemetry, sensor fusion, mission control | 5 V |
| Altimeter | BMP585 | High-precision barometric altimeter and temperature sensor | 3.3 V |
| IMU | BNO086 | 9-axis orientation, acceleration, and altitude estimation | 3.3 V |
| GNSS | NEO-M9N | Quad-constellation positioning and velocity | 5 V |
| Telemetry Radio | SX1276 LoRa | Long-range RF communication (868 MHz) | 3.3 V |
| Camera | M5Stack CAM (OV2640) | Mission imaging and video capture | 5 V |
| Data Logger | MicroSD Module | SPI flight data logging | 3.3 V |
| Buck Converter | MP1584 | Converts 7.4 V to 5 V, up to 3 A, 90–92% efficiency | Input: 7.4 V |
| LDO Regulator | TPS73733 | Converts 5 V to 3.3 V, 1 A, low-noise, high-PSRR | Input: 5 V |
| Surge Protection | SMBJ12A TVS Diode | Transient Voltage clamp-12V, 600 W peak | - |
| Voltage measurement | R-Divider 100k/47k+ADC | Battery voltage → STM32 PA0 ADC | - |
| Power Control | External Toggle Switch | Accessible main power ON/OFF | - |
| Power Indicator | Green LED+330Ω | Power ON visual indicator→PC13 | 3.3V |

## EPS ARCHITECTURE
| Parameter | Specification |
|---|---|
| **Battery** | Samsung INR18650-30Q, 2S1P configuration, 7.4 V, 3000 mAh |
| **Main 5 V Rail** | MP1584 Buck Converter: 7.4 V → 5 V, 3 A max, ~90% efficiency |
| **Logic 3.3 V Rail** | TPS73733 LDO Regulator: 5 V → 3.3 V, 1 A, low-noise output |
| **Power Architecture** | Dual regulated voltage rails with centralized star power distribution |
| **Protection** | Fuse, MOSFET reverse-polarity protection, and TVS surge clamp |
| **Mission Runtime** | Minimum requirement: 2 hours • Estimated operational time: ~7 hours |
| **Total Energy** | 22.2 Wh available • 5.64 Wh required (includes 30% design margin) |

## PAYLOAD BLOCK DIAGRAM
```
Samsung INR18650-30Q
        |
        |
  Toggle switch
        |
MP1584 Buck Converter: 7.4 V → 5 V ----TPS73733 LDO Regulator: 5 V → 3.3 V
        |                                              |__ BMP585
        |__ STM32F405RGT6                              |__ BNO086
        |__ NEO-M9N GPS                                |__ MicroSD card
        |__ M5Stack CAM                                |__ SX1276 LoRa
```
## Battery Comparison

| Parameter | Samsung INR18650-30Q | Panasonic NCR18650GA | Molicel INR21700-P45B |
|---|---|---|---|
| Cell Type | Li-Ion INR18650 | Li-Ion NCR18650 | Li-Ion INR21700 |
| Nominal Voltage | 3.6 V | 3.6 V | 3.6 V |
| Full Charge Voltage | 4.2 V | 4.2 V | 4.2 V |
| Capacity | 3000 mAh | 3500 mAh | 4500 mAh |
| Energy per Cell | 10.8 Wh | 12.6 Wh | 16.2 Wh |
| Maximum Continuous Current | 15 A | 10 A | 45 A |
| Weight per Cell | 48 g | 48 g | 70 g |
| Dimensions | 18.4 × 65 mm | 18.6 × 65 mm | 21 × 70 mm |
| Thermal Stability | Very Good | Excellent | Excellent |
| Cost per Cell | ₹550–650 | ₹700–850 | ₹1000–1200 |

## Battery Configuration Selection

| Configuration | Nominal Voltage | Capacity | Power Flow | Max Discharge Power | Verdict |
|---|---:|---:|---|---:|:---:|
| 1S Single Cell | 3.7 V | 3000 mAh | 3.7 V → Boost → 5 V → LDO → 3.3 V | 9.25 W | Rejected |
| 2S1P Series | 7.4 V | 3000 mAh | 7.4 V → Buck → 5 V → LDO → 3.3 V | 22.2 W | Selected |
| 2P Parallel | 3.7 V | 6000 mAh | 3.7 V → Boost → 5 V → LDO → 3.3 V | 18.5 W | Rejected |

## Power Budget Estimation

| Type | Component | Voltage (V) | Current (mA) | Power (W) | Duty Cycle (%) | Energy (2h) (Wh) | Source |
|---|---|---|---|---|---|---|---|
| MCU | STM32F405 | 3.3 | 110 | 0.363 | 100 | 0.726 | Datasheet |
| Sensor | BMP585 | 3.3 | 0.005 | 0.000016 | 100 | 0.00003 | Datasheet |
| IMU | BNO086 | 3.3 | 18 | 0.059 | 100 | 0.118 | Datasheet |
| GPS | NEO-M9N | 3.3 | 68 | 0.224 | 100 | 0.448 | Datasheet |
| Radio TX | SX1276 LoRa (TX) | 3.3 | 120 | 0.396 | 20 | 0.158 | Datasheet |
| Radio Idle | SX1276 LoRa (Idle) | 3.3 | 10 | 0.033 | 80 | 0.053 | Datasheet |
| Storage | microSD Module | 3.3 | 50 | 0.165 | 100 | 0.330 | Datasheet |
| Camera | M5Stack CAM | 5.0 | 160 | 0.800 | 100 | 1.600 | Datasheet |
| LED | Power LED | 3.3 | 10 | 0.033 | 100 | 0.066 | Estimated |
| Losses | Regulators & Conversion | — | — | 0.420 | 100 | 0.840 | Calculated |
| **TOTAL** |  |  |  | **2.49 W** |  | **4.339 Wh** |  |

## Battery Pack Energy & Mission Analysis

| Parameter | Value |
|---|---|
| Total Available Energy | 22.2 Wh |
| Average Power Consumption | 2.49 W |
| Mission Energy (2 hours) | 4.34 Wh |
| Required Energy (with 30% margin) | 6.47 Wh |
| Battery Voltage | 7.4 V (2S) |
| Capacity | 3000 mAh |
| Safe Runtime | ~7 hours |
| Theoretical Runtime | 8.91 hours |
| Energy Remaining | 15.73 Wh |
| Status | ✅ COMPLIANT |

---

### Energy Calculations

**Battery Energy**
```
Energy = Voltage × Capacity
       = 7.4 V × 3.0 Ah
       = 22.2 Wh
```

**Mission Energy (2 hours)**
```
= 2.49 W × 2 h
= 4.98 Wh
```

**With 30% Safety Margin**
```
= 4.98 Wh × 1.3
= 6.47 Wh
```

**Energy Margin**
```
= 22.2 Wh − 6.47 Wh
= 15.73 Wh
```

**Operating Time**
```
= 22.2 Wh / 2.49 W
= 8.91 hours (theoretical)
```

---

### Notes
- Safe runtime is derated to ~7 hours due to:
  - temperature effects  
  - battery aging  
  - RF transmission bursts  
- System is comfortably above the 2-hour competition requirement with strong margin.

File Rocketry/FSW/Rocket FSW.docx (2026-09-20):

# 6. Flight Control Software Architecture

## 6.1 Introduction

The Model Rocket Flight Control Software (MR FSW) is responsible for managing all onboard operations during the mission lifecycle, including sensor initialization, telemetry handling, flight-state management, data logging, payload deployment logic, and recovery assistance. The software is implemented as a Finite State Machine (FSM) to ensure deterministic behaviour, modularity, and safe execution during all mission phases.

The flight software continuously interfaces with the onboard sensors, telemetry subsystem, SD-card storage, and payload separation mechanisms. The FSM architecture allows the model rocket to autonomously transition between mission phases based on real-time sensor data and predefined logical conditions.

The software architecture has been designed in accordance with the IN-SPACe Model Rocketry India Student Competition 2026 guidelines, which mandate: real-time telemetry transmission at 1 Hz or greater, onboard telemetry backup storage, flight software state indication, recovery from processor reset, payload separation at the target altitude (1000m ± 100m), descent control activation, and telemetry-based mission monitoring.

The onboard flight software operates on the primary STM32 flight computer and communicates with all onboard sensors through I2C, SPI, and UART interfaces. The software continuously acquires altitude, atmospheric pressure, temperature, acceleration, angular velocity, GNSS coordinates, system voltage, and flight-state information. It interfaces with two independent altimeters to ensure redundant and fail-safe recovery operations:

1. Primary Altimeter: A COTS-based barometric sensor integrated into the primary avionics flight computer loop for real-time state estimation and telemetry logging.
2. Backup Altimeter: A redundant, independent COTS altimeter (provided by the InSpace authorities) integrated into the redundant separation chain to trigger payload separation and parachute ejection if the primary system fails.

All telemetry packets are serialized into ASCII comma-separated format and transmitted to the Ground Control Station (GCS) through the RF telemetry subsystem (LoRa) while simultaneously being stored onboard for redundancy.

## 6.2 Finite State Machine (FSM)

The Model Rocket flight software is implemented using a Finite State Machine consisting of the following operational states: BOOT, TEST_MODE, LAUNCH_PAD, ASCENT, PAYLOAD_SEP, DESCENT, AEROBREAK_RELEASE, IMPACT.

The FSM architecture ensures structured mission execution, safe subsystem activation, controlled deployment sequencing, and telemetry continuity. Each state performs dedicated operations and transitions to the next state only after specific conditions are satisfied.

### 6.2.1 BOOT State

The BOOT state is entered immediately after the external power switch of the model rocket is turned ON. During this phase, the onboard computer initializes all hardware and software subsystems, including: the MPU6050/BNO086 IMU, the primary BMP580/BMP585 pressure sensor, the NEO-M9N GNSS receiver, the RF telemetry module (LoRa/Zigbee), the SD-card storage, the voltage monitoring circuitry, and the recovery beacon circuitry.

The following tasks are performed during BOOT: sensor initialization, communication bus initialization, SD-card mounting, loading previous state information, telemetry initialization, and internal health diagnostics.

The software checks sensor communication status, telemetry subsystem availability, SD-card accessibility, and power-system health. If any critical subsystem fails initialization, the software logs the error to onboard storage, attempts re-initialization once, and continues to TEST_MODE with the failed subsystem marked as unavailable.

The BOOT state also restores the previous mission state from onboard storage in the event of a processor reset during flight, ensuring compliance with mission requirements regarding state recovery after reboot.

### 6.2.2 TEST_MODE State

After successful initialization, the software transitions into TEST_MODE. The purpose of this state is to validate all onboard subsystems before launch.

During TEST_MODE: all sensors perform live-data acquisition, telemetry packets are generated, SD-card logging is tested, telemetry links are verified, and sensor values are checked for validity.

The system performs demo telemetry transmission, packet integrity validation, sensor availability checks, and communication verification with the Ground Control Station.

If any abnormality is detected, the system logs an error code to onboard storage, transmits the error through telemetry, and continues to LAUNCH_PAD with degraded functionality noted. If all checks pass successfully, the software transitions into the LAUNCH_PAD state.

### 6.2.3 LAUNCH_PAD State

The LAUNCH_PAD state represents the pre-launch operational phase. During this phase: all sensors remain active, telemetry transmission begins at 1 Hz, and calibration commands may be received from the Ground Control Station.

The following calibrations are performed: gyroscope zero-offset calibration, barometric pressure calibration, accelerometer bias calibration, and launch-pad altitude reference calibration. The launch-pad altitude is defined as the zero-reference altitude for the mission.

Telemetry data and current FSM state are periodically written to onboard storage to enable state recovery after reset. The software remains in this state until launch conditions are detected.

#### Launch Detection Logic

The transition from LAUNCH_PAD to ASCENT uses sensor cross-verification to improve reliability. The primary launch indicator is sudden sustained acceleration detected through the IMU. The secondary confirmation is positive altitude change detected by the primary barometric altimeter.

The transition logic is implemented as: acceleration magnitude exceeds a predefined threshold, sustained for a fixed time interval, and altitude rises above a small threshold value. This prevents false launch triggers caused by vibration, handling shock, or sensor noise.

### 6.2.4 ASCENT State

The ASCENT state begins once rocket launch has been confirmed. During this phase: all telemetry data is continuously transmitted, sensor data is logged to onboard storage, and real-time state information is sent to the Ground Control Station.

The flight computer collects altitude, pressure, temperature, GNSS coordinates, acceleration, angular velocity, and voltage data. All telemetry packets are serialized into comma-separated ASCII format before transmission over the RF telemetry channel. The ascent phase continues until apogee or ejection conditions are detected.

#### Apogee / Separation Detection

The transition from ASCENT to PAYLOAD_SEP is determined primarily using altitude trend analysis. The software continuously computes vertical velocity using consecutive altitude samples from the primary altimeter. When altitude reaches a peak and sustained negative vertical velocity is observed, the software confirms apogee. This method is more reliable than using accelerometer direction alone, as barometric altitude provides better long-term stability for apogee detection.

If the primary flight computer fails to detect apogee, the backup altimeter (provided by InSpace) operates in parallel on a redundant circuit to independently trigger the separation event.

### 6.2.5 PAYLOAD_SEP State

The PAYLOAD_SEP state is activated immediately upon apogee detection at the target altitude (1000m ± 100m). During this state, the flight computer initiates the payload separation and drogue parachute deployment sequence.

The software commands the servo actuator to release the mechanical latch of the spring ejection mechanism. This ejects the CAN-7U sized satellite (payload) and deploys the primary stage (drogue parachute) to stabilize the descent of the rocket. Telemetry transmission rates remain at 1 Hz, indicating payload separation status. Once deployment is confirmed via telemetry and sensor validation, the software transitions to the DESCENT state.

### 6.2.6 DESCENT State

The DESCENT state begins immediately after payload separation. During this state: the primary drogue parachute is active, the descent rate is monitored, and stabilization is achieved.

The primary parachute is intended to reduce tumbling, stabilize the model rocket body, and maintain telemetry link reliability. The parachute system is designed to maintain descent rates between 2 to 5 m/s (as mandated by guidelines). During this phase, sensor data fusion is used to continuously track altitude, descent speed, and orientation.

### 6.2.7 AEROBREAK_RELEASE State

The AEROBREAK_RELEASE state is activated when the rocket is in the DESCENT state and the altitude falls below a secondary threshold (600m ± 10m).

Once the activation condition is met, the secondary recovery or main parachute mechanism is deployed to further decelerate the rocket body for a safe landing. This state transition is strictly gated by the FSM to prevent accidental premature deployment during ascent or early descent. Sensor data continues to be logged and telemetered continuously.

### 6.2.8 IMPACT State

The IMPACT state represents touchdown and mission completion. This state is triggered using low-altitude detection combined with a sudden deceleration spike measured by the IMU. Typical conditions include altitude near ground level and a significant deceleration spike.

During IMPACT: the audio recovery beacon is activated, final telemetry packets are transmitted, and onboard data files are finalized. The recovery beacon assists in locating the rocket body. Future implementation may dynamically reduce beacon intensity based on GNSS proximity or radio signal strength to optimize post-landing power consumption.

Flow Chart showing change of states

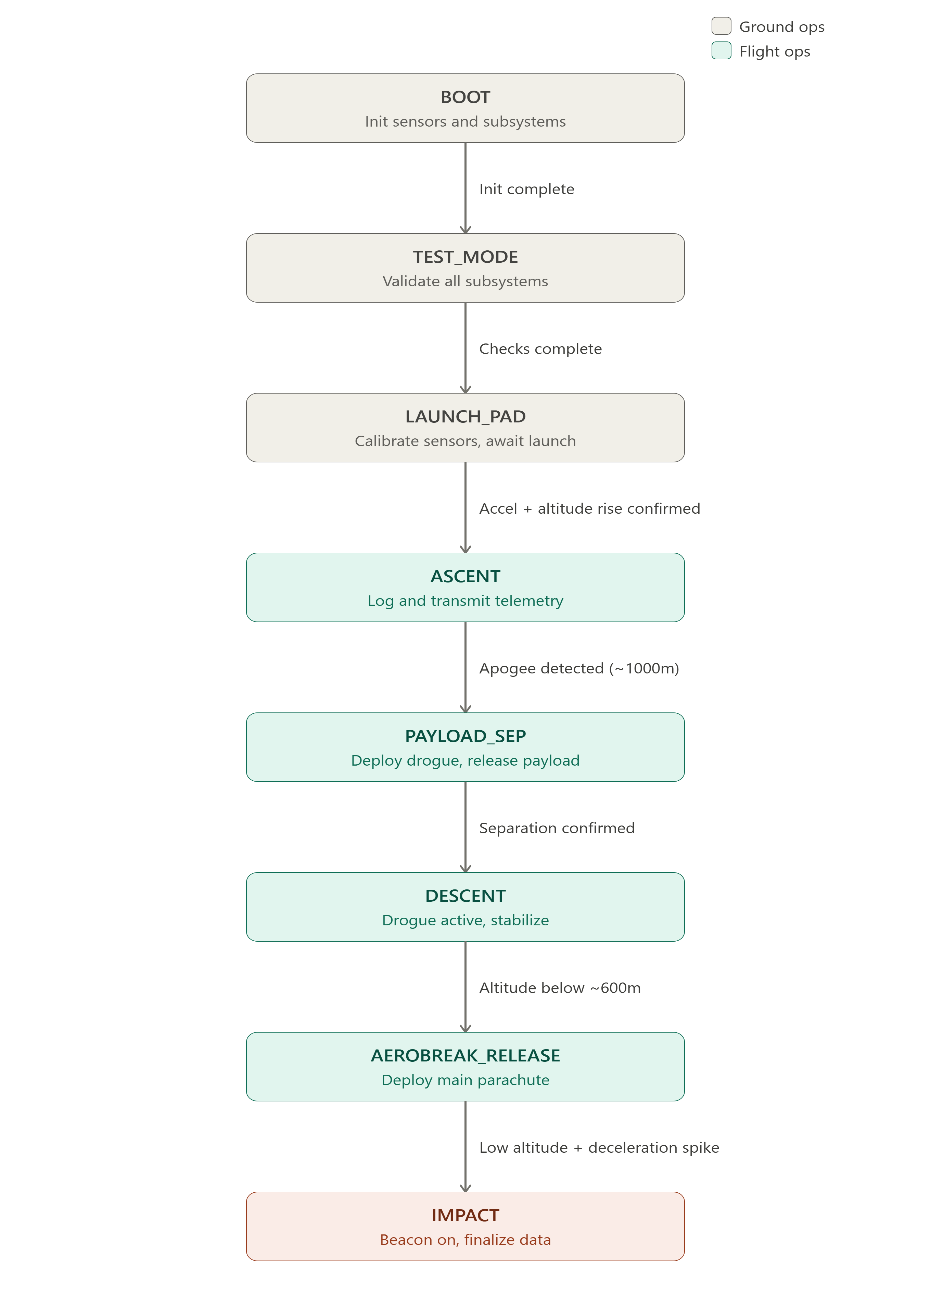
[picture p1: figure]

## 6.4 Software Architecture and Module Overview

1. FSW Core: The main central controller of the entire model rocket system, acting as the OS that orchestrates all other modules. Maintains the state machine with a pointer to the currently executing state, decides when to move to the next state, and decides how to allocate CPU cycles, set sampling rates, and manage execution priority. Has master control over all other modules but also accepts inbound signals from them (aka interrupts in case of faults being raised).
2. Data Layer: An abstraction layer that sits between raw sensor data and the decision logic in FSW Core. It contains data structures and functions that process higher-level interpretations of system state, for example, fusing accelerometer and altimeter readings to determine with high confidence whether the rocket is ascending, has reached apogee, or is descending.
3. Hardware Controller Layer: Directly interfaces with all onboard sensors and hardware peripherals. Each hardware and avionic component has its own dedicated component submodule. It receives control signals asynchronously from FSW Core. Data acquisition strategy utilizes a shared memory model where each controller writes continuously to an assigned buffer that FSW polls, balancing latency and synchronization complexity.
4. Communication Layer: Manages all external interfaces, primarily the ground station link. Responsible for receiving inbound commands from the ground station and relaying them to FSW Core for interpretation, and for serializing outgoing telemetry data into well-formed packets and forwarding them to the Hardware Controller for transmission.
5. Configuration Module: A centralized configuration module, implemented as header files like config.h, that stores all magic numbers, decision thresholds, and tunable constants used across the system. It also includes shared types in types.h read by the FSW to initialize all submodules.
6. TestAndSim Suite: Acts as a drop-in replacement for the Hardware Controller Layer during ground testing, feeding predefined or procedurally generated sensor data into the rest of the system. Simulated inputs include controlled randomness to stress-test decision logic, supporting both boundary-condition testing and blackbox testing of the full FSW pipeline without physical hardware.

### Tasks overview for FreeRTOS

- TaskIMU: Periodically reads accelerometer, gyroscope, and attitude data from the BNO086 and updates the shared IMU buffer. Sampling rate is controlled dynamically by FSWCore.
- TaskBaro: Periodically reads BMP580/BMP585 pressure and temperature data, computes altitude estimates, and updates the shared barometric buffer. Sampling rate is controlled dynamically by FSWCore.
- TaskGNSS: Parses UBX-NAV-PVT data from the NEO-M9N and updates the shared GNSS buffer with position, altitude, UTC time, satellite count, and fix validity.
- TaskDataLayer: Fuses IMU and barometric data from the primary altimeter to estimate altitude and vertical velocity, evaluates flight condition flags, and updates the shared AbstractState buffer.
- TaskFSM: Main 10 Hz orchestration task managing FSM transitions, command handling, watchdog feeding, deployment actions, task rate notifications, and state persistence.
- TaskTelemetry: Builds telemetry packets from shared system data, transmits them over the RF link (LoRa/Zigbee), queues them for SD logging, and opens the radio receive window.
- TaskCommRx: Waits for the RF transceiver to receive interrupts, validates incoming packets, forwards valid commands to FSWCore, and sends ACK responses.
- TaskSDWrite: Writes telemetry and state data to the SD card, ensures persistent storage with flushing, and reports storage faults non-fatally.
- TaskHealthMonitor: Runs at 1 Hz to monitor voltage and system faults, logs fault events, and updates telemetry fault flags.
- TaskRecoveryBeacon: Remains dormant until the FSM transitions to the IMPACT state, then activates the audio beacon and periodically transmits the final GPS recovery coordinates over the RF link before suspending permanently.

### Sampling Rate for various tasks:

Task | Module | BOOT | TEST | LAUNCH_PAD | ASCENT | PAYLOAD_SEP | DESCENT | AEROBREAK_RELEASE | IMPACT
TaskIMU | HardwareController | 10 Hz | 10 Hz | 10 Hz | 100 Hz | 50 Hz | 100 Hz | 100 Hz | 10 Hz
TaskBaro | HardwareController | 5 Hz | 5 Hz | 5 Hz | 20 Hz | 10 Hz | 20 Hz | 20 Hz | 2 Hz
TaskGNSS | HardwareController | 1 Hz | 1 Hz | 5 Hz | 5 Hz | 5 Hz | 5 Hz | 5 Hz | 1 Hz
TaskDataLayer | DataLayer | 5 Hz | 5 Hz | 5 Hz | 20 Hz | 10 Hz | 20 Hz | 20 Hz | 2 Hz
TaskFSM | FSWCore | 10 Hz | 10 Hz | 10 Hz | 10 Hz | 10 Hz | 10 Hz | 10 Hz | 10 Hz
TaskHealthMonitor | FSWCore | 1 Hz | 1 Hz | 1 Hz | 1 Hz | 1 Hz | 1 Hz | 1 Hz | 1 Hz
TaskTelemetry | CommLayer | off | off | 1 Hz* | 1 Hz | 1 Hz | 1 Hz | 1 Hz | final TX
TaskCommRx | CommLayer | off | off | intr. | intr. | intr. | intr. | intr. | off
TaskSDWrite | HardwareController | 1 Hz | 1 Hz | 1 Hz | 1 Hz | 1 Hz | 1 Hz | 1 Hz | finalise
TaskRecoveryBeacon | CommLayer | dormant | dormant | dormant | dormant | dormant | dormant | dormant | once

* TaskTelemetry activates on CMD_START_TELEMETRY from GCS, expected during LAUNCH_PAD.

* TaskFSM and TaskHealthMonitor hold constant rate across all states.

* All other periodic tasks updated by FSWCore via xTaskNotify on each state transition.

* Interrupt driven (RX-done ISR), no fixed rate.

Sequencing diagrams for the various tasks are on the next page with a high level overview.

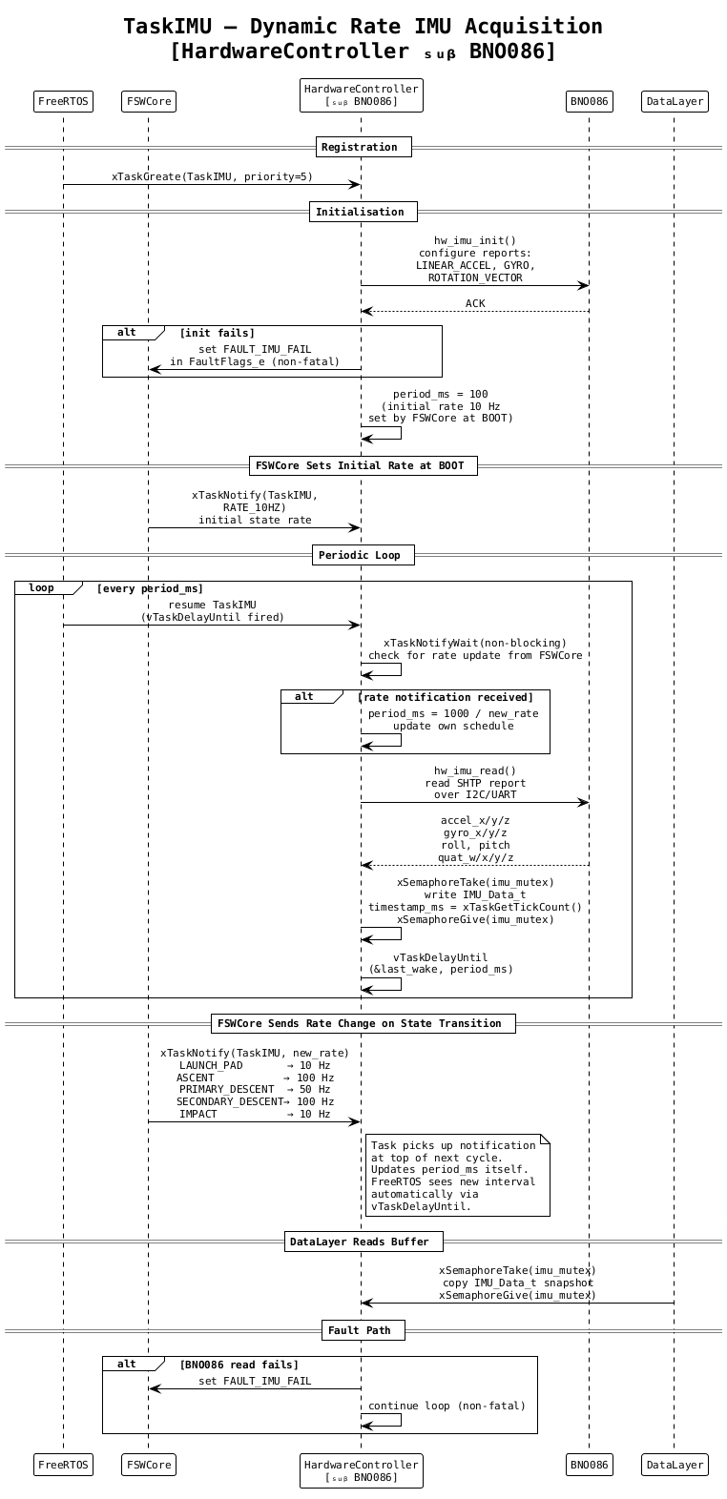
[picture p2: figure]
C:\Users\singh\AppData\Local\Microsoft\Windows\INetCache\Content.MSO\A67F030.tmp
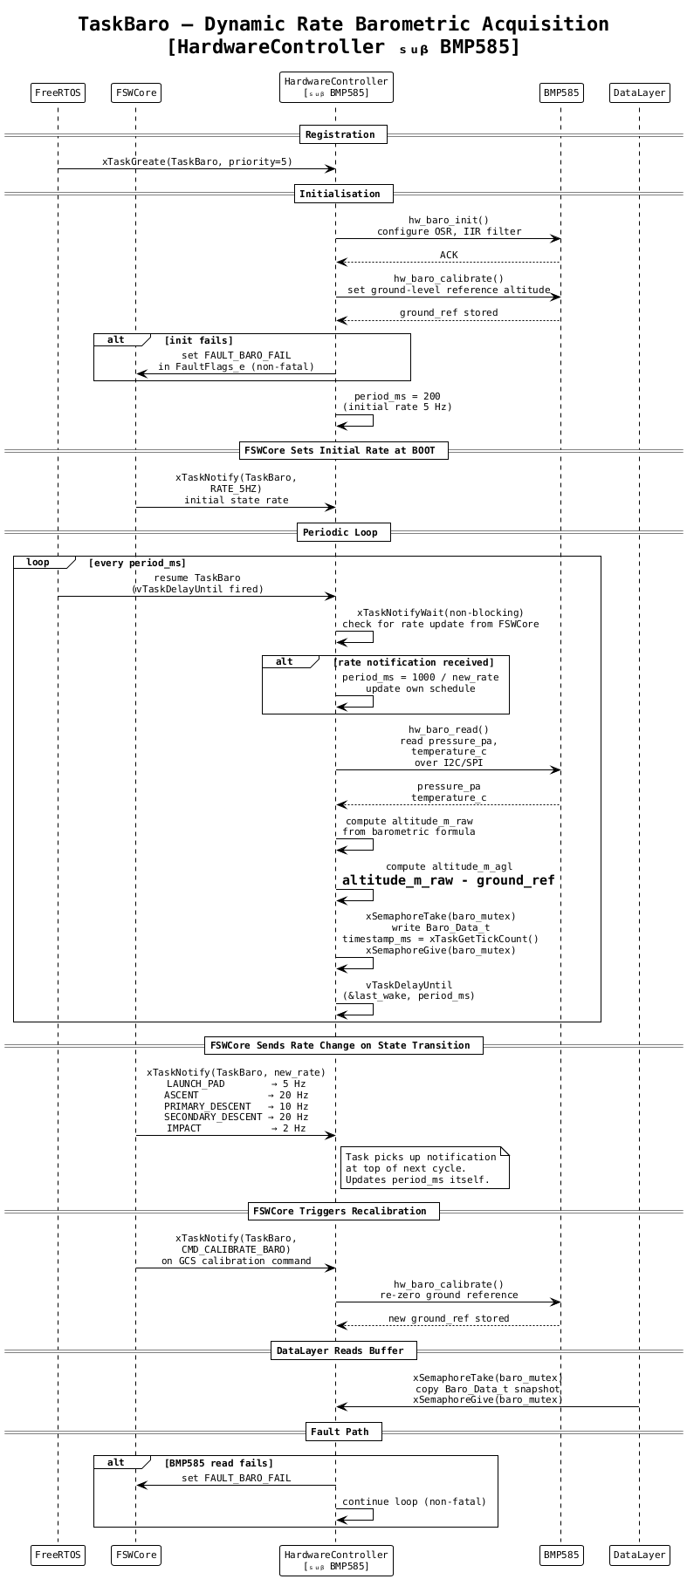
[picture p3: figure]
C:\Users\singh\AppData\Local\Microsoft\Windows\INetCache\Content.MSO\138835BE.tmp
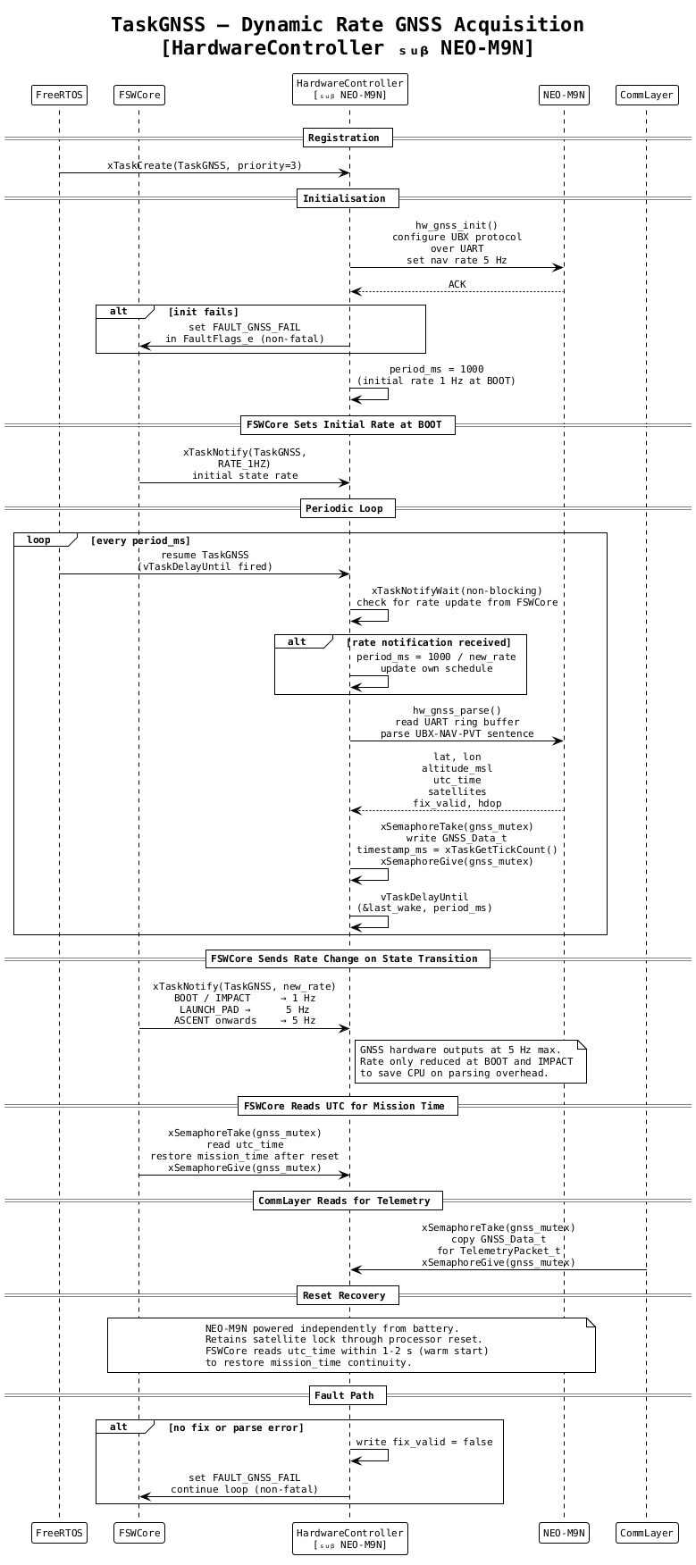
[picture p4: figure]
C:\Users\singh\AppData\Local\Microsoft\Windows\INetCache\Content.MSO\ABE5287C.tmp
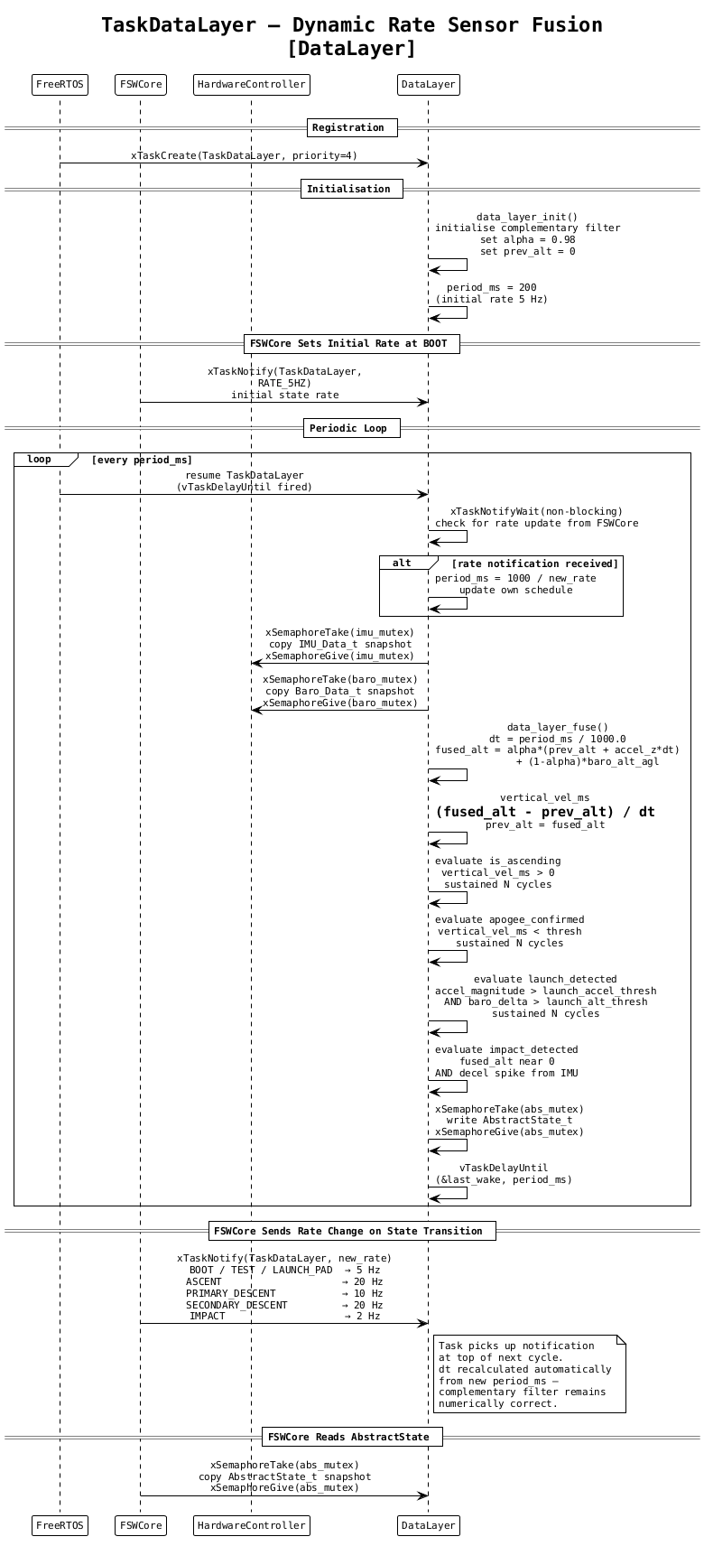
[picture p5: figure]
C:\Users\singh\AppData\Local\Microsoft\Windows\INetCache\Content.MSO\D40DAFEA.tmp
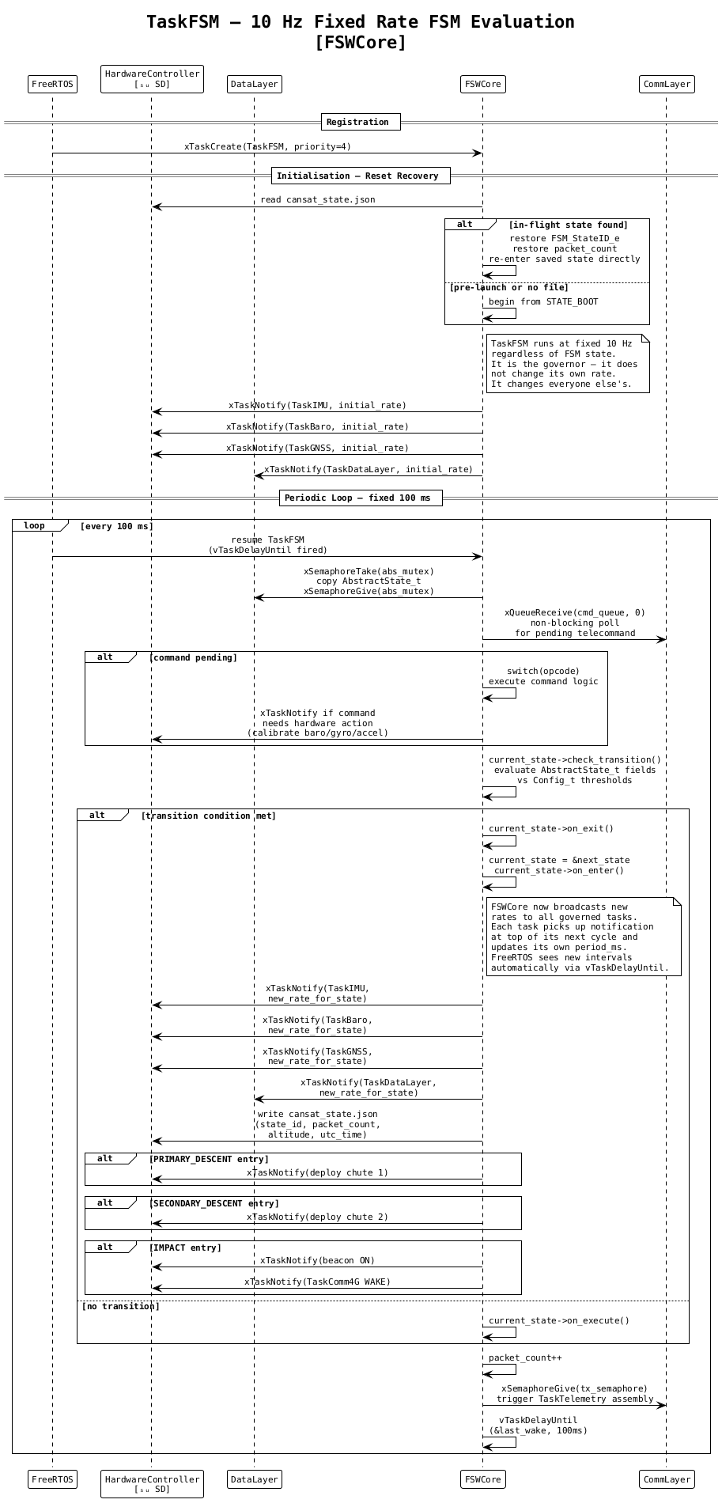
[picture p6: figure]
C:\Users\singh\AppData\Local\Microsoft\Windows\INetCache\Content.MSO\698A9F88.tmp
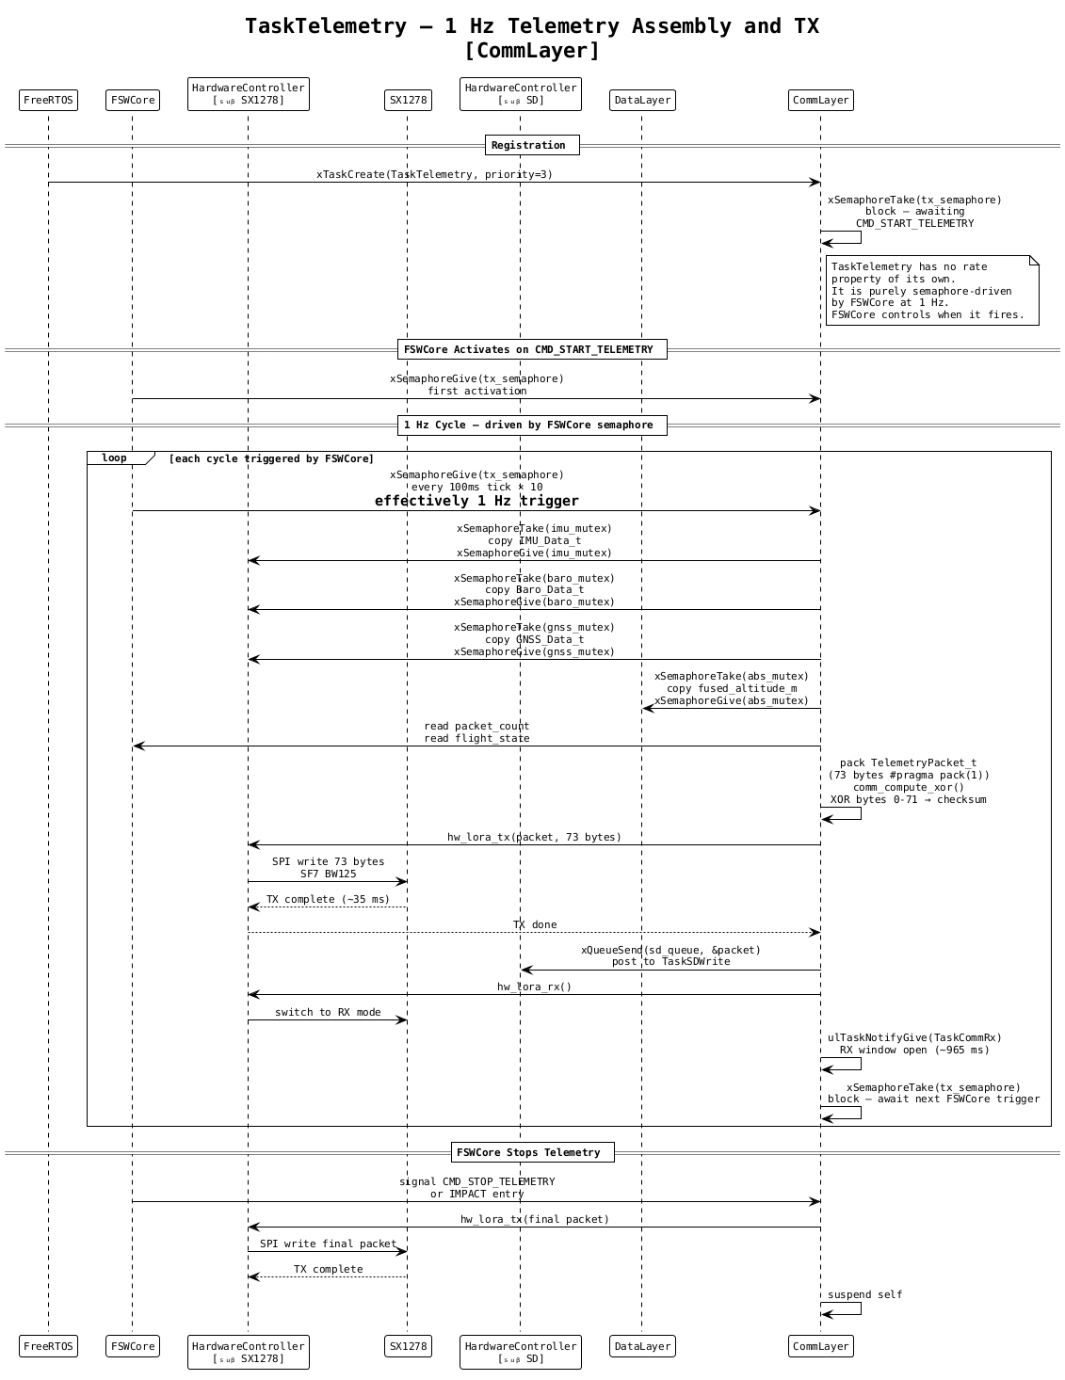
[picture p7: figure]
C:\Users\singh\AppData\Local\Microsoft\Windows\INetCache\Content.MSO\9BB196D6.tmp
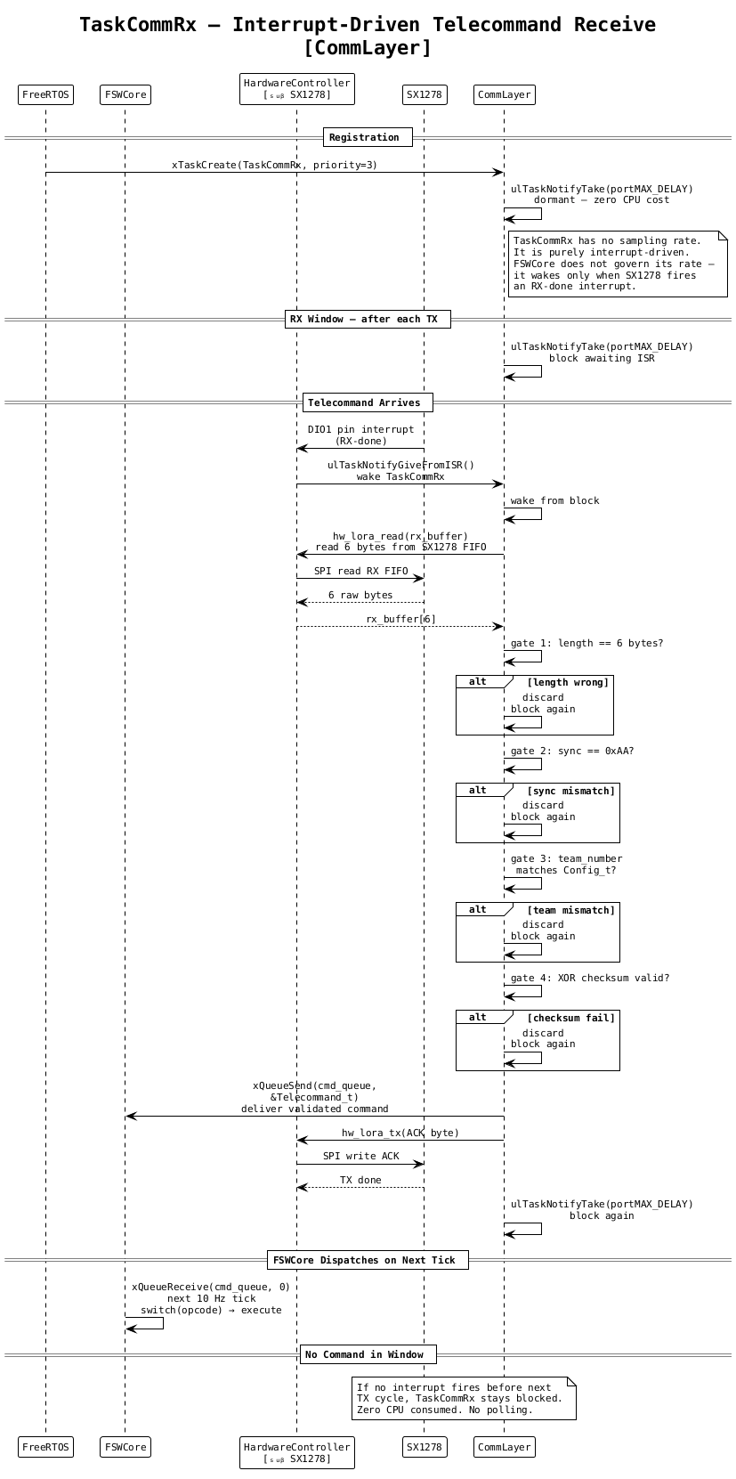
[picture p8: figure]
C:\Users\singh\AppData\Local\Microsoft\Windows\INetCache\Content.MSO\D35AE154.tmp
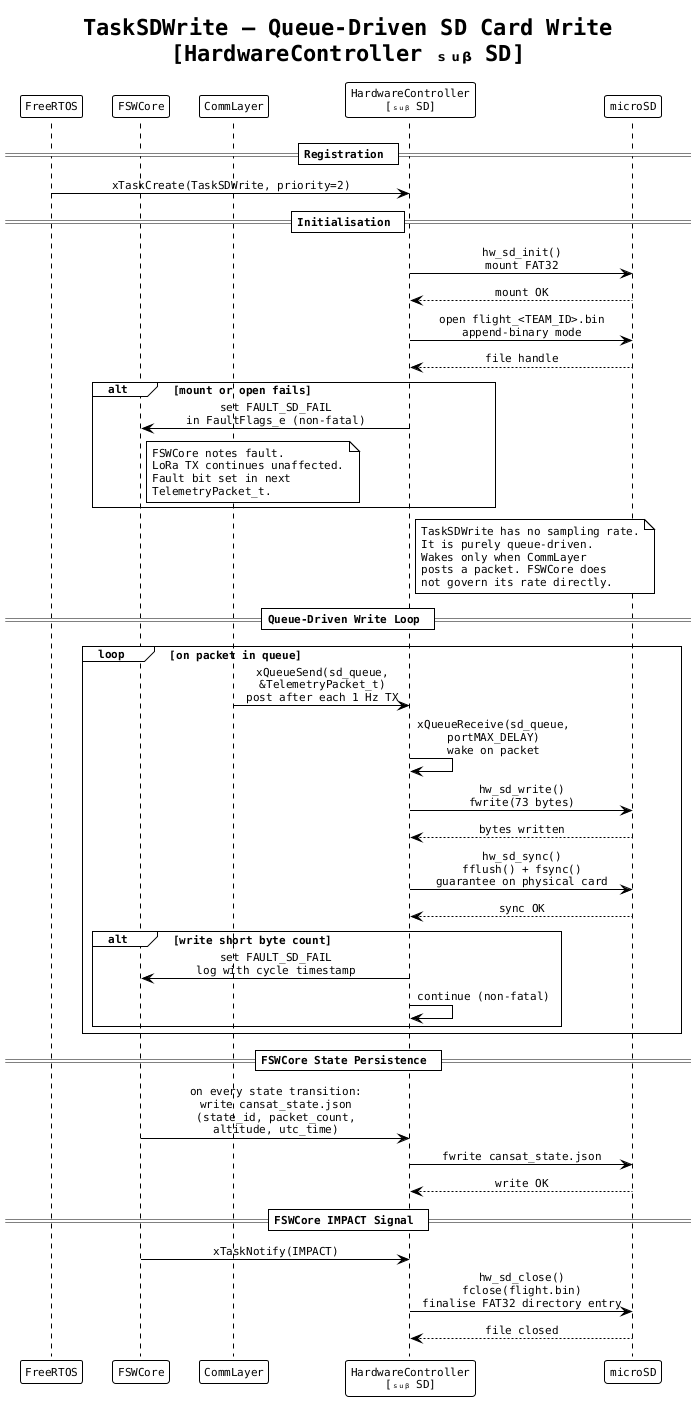
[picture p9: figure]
C:\Users\singh\AppData\Local\Microsoft\Windows\INetCache\Content.MSO\6725682.tmp
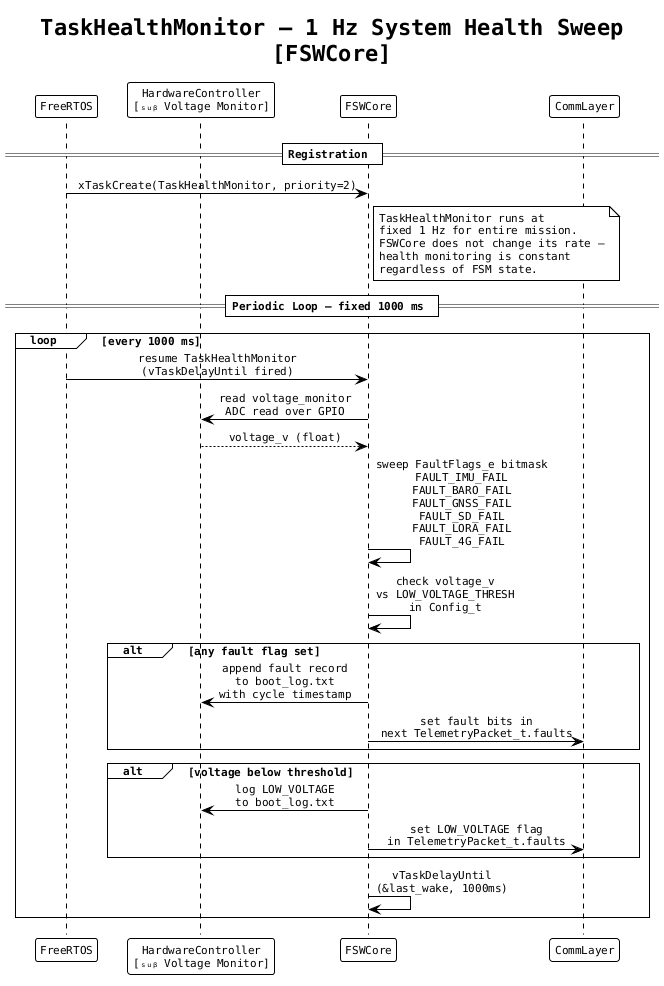
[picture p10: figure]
C:\Users\singh\AppData\Local\Microsoft\Windows\INetCache\Content.MSO\F31B39E0.tmp

## 6.5 Telemetry and Telecommand Details

### 6.5.1 Communication Architecture Overview

The Model Rocket Flight Software implements a bidirectional RF communication link between the Onboard Telemetry Unit and the Ground Control Station using the Ra-01H SX1262 LoRa module (or XBee/Zigbee transceiver) operating at 868 MHz.

The link carries two distinct traffic classes. Downlink telemetry flows from the Onboard Telemetry Unit (OTU) to the GCS at 1 Hz carrying all sensor, state, and housekeeping data. Uplink telecommands flow from the GCS to the OTU carrying operator instructions for calibration, state transitions, and transmission control. The radio transmits the telemetry packet and then immediately switches to receive mode, listening for any incoming telecommand. This half-duplex timing arrangement ensures telemetry is never interrupted by command reception and commands are never missed.

The Communication Layer within the FSW layered architecture is solely responsible for managing both traffic classes. It provides a clean upward interface to FSW Core for command delivery and state reporting, and a clean downward interface to the Hardware Controller Layer for physical transmission and reception.

### 6.5.2 Downlink Telemetry

#### Transmission Trigger and Rate

Upon receiving the CMD_START_TELEMETRY telecommand from the GCS, the FSW begins transmitting one telemetry packet per second continuously. Telemetry is not transmitted autonomously at power-on. The GCS must explicitly command transmission. Transmission continues until a CMD_STOP_TELEMETRY command is received or the IMPACT state is reached, at which point the final packet is transmitted, the SD card is finalized, and the recovery beacon is activated.

#### Serialization Approach — Direct Binary Serialization

To minimize air time and duty cycle, Direct Binary Serialization was selected for over-the-air transmission, combined with ASCII CSV regeneration on the GCS side.

All telemetry fields are packed into a fixed-layout C struct and the raw bytes of that struct are transmitted over the link. The total struct size is 73 bytes, which reduces air time and duty cycle to approximately 3 percent, well within ISM band self-management guidelines.

On the GCS side, the received 73 bytes are validated and then deserialized back into named fields. The GCS Ground Station software then regenerates the ASCII CSV line from those fields and writes it to the log file. The output format is fully compliant with the 16 mandatory fields specified in Annexure-2 of the guidelines:

<TEAM ID>, <TIME STAMPING>, <PACKET COUNT>, <ALTITUDE>, <PRESSURE>, <TEMP>, <VOLTAGE>, <GNSS TIME>, <GNSS LATITUDE>, <GNSS LONGITUDE>, <GNSS ALTITUDE>, <GNSS SATS>, <ACCELEROMETER DATA>, <GYRO SPIN RATE>, <FLIGHT SOFTWARE STATE>, <ANY OPTIONAL DATA>

#### Telemetry Struct Definition

The telemetry packet is defined as a packed C struct to guarantee no padding bytes are inserted between fields:

#pragma pack(1)
typedef struct {
uint16_t team_number; // 2 bytes -- numeric team ID (e.g. 42)
uint32_t mission_time; // 4 bytes -- seconds since power-on
uint16_t packet_count; // 2 bytes -- sequential cycle counter
float altitude; // 4 bytes -- altitude relative to ground AGL (m)
float pressure; // 4 bytes -- atmospheric pressure (Pa)
float temperature; // 4 bytes -- temperature (Celsius)
float voltage; // 4 bytes -- system voltage (Volts)
uint32_t gnss_time; // 4 bytes -- HHMMSS as integer
float latitude; // 4 bytes -- decimal degrees
float longitude; // 4 bytes -- decimal degrees
float gnss_altitude; // 4 bytes -- metres MSL
uint8_t gnss_sats; // 1 byte -- satellite count
float accel_x; // 4 bytes -- acceleration X (m/s²)
float accel_y; // 4 bytes -- acceleration Y (m/s²)
float accel_z; // 4 bytes -- acceleration Z (m/s²)
float gyro_spin_rate; // 4 bytes -- spin rate (deg/s)
uint8_t flight_state; // 1 byte -- FSW state enum as uint8
uint8_t checksum; // 1 byte -- XOR of bytes 0 through 71
} __attribute__((packed)) TelemetryPacket_t;
#pragma pack()

#### Telemetry Field Summary

S.No. | Field | Resolution | Source | Bytes
1 | team_number | Integer | Hardcoded config | 2
2 | mission_time | 1 second | System Clock | 4
3 | packet_count | Integer | FSW Core | 2
4 | altitude | 0.1 m | Data Layer fused (Primary altimeter) | 4
5 | pressure | 1 Pa | BMP580/BMP585 | 4
6 | temperature | 0.1 °C | BMP580/BMP585 | 4
7 | voltage | 0.01 V | Voltage Monitor ADC | 4
8 | gnss_time | HHMMSS | NEO-M9N | 4
9 | latitude | 0.0001° | NEO-M9N | 4
10 | longitude | 0.0001° | NEO-M9N | 4
11 | gnss_altitude | 0.1 m | NEO-M9N | 4
12 | gnss_sats | Integer | NEO-M9N | 1
13-15 | accel_x/y/z | 0.01 m/s² | MPU6050/BNO086 | 12
16 | gyro_spin_rate | 0.1°/s | MPU6050/BNO086 (Mechanical Gyro Spin) | 4
17 | flight_state | Enum uint8 | FSW Core (FSM State) | 1
18 | checksum | XOR uint8 | Comm. Layer | 1
| Total | | | 73 bytes

#### Packet Integrity — XOR Checksum

A single XOR checksum byte is computed over all 72 preceding bytes of the struct and stored as the final field before transmission. The receiver recomputes this XOR independently and compares it against the received checksum byte to catch any bit-flip corruption before deserialization is attempted.

#### Packet Counter and Drop Detection

The packet_count field is an unsigned 16-bit integer maintained by FSW Core that increments by one every telemetry cycle unconditionally. GCS detects dropped or corrupted packets by verifying that each received packet's counter is exactly one greater than the previous accepted packet's counter.

#### GCS Deserialization and CSV Regeneration

On the GCS side, the received 73 bytes are validated through length, checksum, and team number filters. Once validated, the GCS ground software deserializes the fields, formats them to the required resolution, prepends the full TEAM_ID string (e.g. 2026 IN-SPACe-XXX), and writes it as an ASCII CSV row to the Flight_<TEAM_ID>.csv file.

#### Telemetry Data Flow

Raw sensor readings are collected every cycle from the barometric sensor, IMU, GNSS module, and voltage monitor. The Data Layer processes these to produce clean abstract estimates including the fused altitude. FSW Core evaluates state machine transition conditions, increments the packet counter, and updates the flight_state. The Communication Layer computes the XOR checksum and writes the 73-byte raw block to the RF transmitter and the SD card submodule.

#### Transmission Cycle Timing Budget

The 1 Hz main loop completes sensor reads, data fusion, FSM state evaluation, checksum computation, SD card writing, and RF transmission within approximately 50 milliseconds, leaving approximately 950 milliseconds of the cycle budget in receive mode listening for telecommands.

### 6.5.3 Uplink Telecommand System

#### Design Approach — Hexadecimal Packetized Command Structuring

Telecommands from the GCS to the rocket use Hexadecimal Packetized Command Structuring. Each command is encoded as a fixed 6-byte binary packet in which a unique one-byte hexadecimal opcode identifies the command to be executed.

#### Telecommand Packet Structure

The telecommand packet is a fixed 6-byte sequence:

1. Sync Byte (0xAA)
2. Team Number (16-bit unsigned integer) - 2 bytes
3. Opcode (8-bit command identifier) - 1 byte
4. Parameter (8-bit argument, or 0x00 if unused) - 1 byte
5. Checksum (XOR checksum of preceding 5 bytes) - 1 byte

#### Opcode Table

Opcode | Command | Valid FSW States | Action
0x01 | CMD_START_TELEMETRY | LAUNCH_PAD | Begin 1 Hz binary telemetry transmission
0x02 | CMD_STOP_TELEMETRY | Any | Halt RF telemetry transmission
0x03 | CMD_CALIBRATE_BARO | LAUNCH_PAD | Zero BMP580/BMP585 altitude to ground level
0x04 | CMD_CALIBRATE_GYRO | LAUNCH_PAD | Zero gyroscope bias offsets
0x05 | CMD_CALIBRATE_ACCEL | LAUNCH_PAD | Zero accelerometer offsets
0x06 | CMD_ENTER_TEST | BOOT | Transition FSW to TEST_MODE
0x07 | CMD_ENTER_LAUNCHPAD | TEST_MODE | Transition FSW to LAUNCH_PAD
0x08 | CMD_SWITCH_CHANNEL | Any | Switch transceiver to backup RF channel
0x09 | CMD_TRIGGER_SEP | ASCENT | Manual override to trigger payload separation

#### Telecommand Receive Window and Half-Duplex Management

Because the RF transceiver operates in half-duplex mode, the radio explicitly switches to receive mode for 950 milliseconds of each 1 Hz cycle. If a command arrives, the radio raises a receive-complete interrupt, the Hardware Controller reads the bytes, and the Communication Layer processes and executes the command on the next FSM tick.

#### Receiver Validation and Dispatch

Received bytes are passed to the Communication Layer to apply length verification, sync byte check, team number matching, and XOR checksum validation. Only packets passing all four gates are dispatched to the opcode switch-case for execution.

### 6.5.4 RF Interference Mitigation Plan

To prevent inter-team RF interference at the launch site, the following measures are incorporated:

1. Sync Word Isolation: The transceiver sync word is set to a team-specific value derived from the assigned team number.
2. Software Filtering: The team number is embedded in both telemetry and command packets for software-level verification.
3. Low Duty Cycle: Telemetry packets occupy a very low transmission time (30-35ms), keeping the radio silent 97% of the cycle.
4. Frequency Agility: Backup RF channels (e.g. 861.5 MHz and 869.0 MHz) are pre-configured in firmware and can be dynamically activated via GCS command if primary frequency interference is detected.

## 6.6 Data Storage and Handling

### Storage Strategy

To prevent data loss in case of telemetry link failure, the flight software performs an unconditional parallel write of every telemetry packet to the onboard SD card. Storing binary structs rather than ASCII CSV ensures compactness (reducing flight log size by half) and speed (writing 73 raw bytes avoids the overhead of sprintf).

### Onboard File Structure

Three files are maintained on the FAT32 SD card:

1. flight_<TEAM_ID>.bin: The binary flight log appended with one 73-byte telemetry struct every cycle.
2. rocket_state.json: The FSW state persistence file written at every state transition to recover the operating state after reset.
3. boot_log.txt: A plain text log of boot events, fault flags, state transitions, and SD write errors.

### Standard SD Card Write Process

The SD card is formatted as FAT32 and interfaced via the SPI bus. It is mounted once at BOOT. If mounting fails, the FSW Core raises a non-fatal fault flag but continues initialization and operation normally, ensuring SD card faults never block the FSM or telemetry. The binary log file is kept open throughout the mission to minimize latency and avoid FAT32 directory entry corruption from power cuts during close operations.

### FSW State Persistence Across Processor Reset

The FSW implements mid-flight reset recovery through the rocket_state.json file. The file records the current state, current packet counter, last known fused altitude, and GPS UTC timestamp at the time of transition.

Upon reboot, FSW Core reads rocket_state.json. If it contains an in-flight state (ASCENT, PAYLOAD_SEP, DESCENT, or AEROBREAK_RELEASE), FSW Core restores the FSM to that state directly, restores the packet counter, and resumes telemetry transmission within 5 seconds of reboot without traversing the pre-launch sequence.

### Post-Flight Data Retrieval

Following landing and recovery, the binary file flight_<TEAM_ID>.bin is retrieved from the SD card. A conversion utility script on the GCS reads the binary file sequentially, validates the checksums, and regenerates the GCS-compliant Flight_<TEAM_ID>.csv for judge evaluation.

### Data Integrity Measures Summary

Measure | Implementation | Failure Mode Addressed
XOR Checksum | Computed over bytes 0-71, stored as byte 72 | RF bit-flip corruption and SD read errors
Four-Gate GCS Validation | Length, checksum, team number, and deserialization filters | Malformed packets, corruption, and inter-team interference
fflush/fsync on SD Write | Called immediately after every binary write | Data loss from power cut before buffer drain at impact
Unconditional SD Write | Runs every cycle from BOOT | RF link loss during any flight phase
State Persistence File | Written to rocket_state.json at every state transition | Mid-flight processor reset causing state and counter loss
RF Sync Word | Set to team-specific value in transceiver hardware | Physical-layer inter-team interference

## 6.7 Simulation Mode Strategy

### Overview

The TestAndSim suite is a dedicated FSW module activated by a compile-time flag in config.h for ground testing. When active, it replaces sensor acquisition tasks with simulation counterparts while keeping storage, FSM logic, and telemetry tasks identical to flight firmware. Rather than acquiring live sensor data, it injects procedurally generated data directly into the shared sensor buffers, making the simulation entirely transparent to the rest of the FSW.

### SimDriver_t

All simulation states are owned by the SimDriver_t struct, which holds simulated readings, scenario identifiers, simulation tick counters, and a fault injection field of type FaultFlags_e to simulate sensor failures. The noise model and physical model parameters are configurable to allow deterministic regression runs and randomized stress testing.

### Some Example Scenarios

- Nominal Flight Scenario: Models a complete mission profile from BOOT through IMPACT following the expected altitude (1000m) and velocity envelope.
- Apogee Edge Case Scenario: Models a slow, shallow apogee profile to test apogee detection debouncing in the Data Layer.
- Launch Detection Edge Case: Applies vibration-level accelerations to verify that launch detection logic ignores handling shock.
- Processor Reset Scenario: Injects a simulated reset during ASCENT to verify that FSM state and packet counters are successfully restored from rocket_state.json.

## 6.8 Test Methodology

### Overview

The FSW test strategy is structured across unit testing of individual module functions (white-box) and integration testing of the complete FSW pipeline (black-box) via the TestAndSim suite.

### White-Box Unit Testing

Executed on the development host without requiring FreeRTOS or physical hardware to verify:

- FSM transition conditions in FSW Core.
- Complementary filter correctness in the Data Layer.
- Packet serialization and checksum calculations in the Communication Layer.
- SD write sequences and fault flag propagation.

### Black-Box Integration Testing

Integration tests drive the FSW through TestAndSim scenarios, evaluating:

- FSM Correctness: Verifies the FSM traverses states in the correct order (BOOT -> TEST_MODE -> LAUNCH_PAD -> ASCENT -> PAYLOAD_SEP -> DESCENT -> AEROBREAK_RELEASE -> IMPACT) with no skipped or repeated transitions.
- Packet Counter Integrity: Verifies packet counters increment by exactly one and recover correctly from reset.
- Boundary Condition Compliance: Tests all FSM transition thresholds (launch, apogee, 600m deployment, touchdown) at boundary limits.
- Fault Tolerance: Verifies the system enters degraded modes but never stalls or loops indefinitely.

## 6.9 Software Reset Loop

### Reset Detection and State Recovery

On every power-on or reset, the first action of TaskFSM is to attempt to read rocket_state.json from the SD card.

- File does not exist: Clean boot. FSW proceeds normally: BOOT -> TEST_MODE -> LAUNCH_PAD.
- Pre-launch state present: Reset occurred before flight. The FSW restarts the pre-launch sequence.
- In-flight state present: Mid-flight reset detected. FSW skips the pre-launch sequence, restores the FSM state, packet counter, and fused altitude, and resumes telemetry within 5 seconds.

### Watchdog Timer

A hardware watchdog timer is configured with a 2000ms window. TaskFSM feeds the watchdog once per 10 Hz cycle. If any task deadlocks or the scheduler hangs, the watchdog forces a reset, triggering the state recovery sequence.

## 6.10 Proto Version Testing Details

Proto version testing is conducted on assembled hardware before final integration to verify that each subsystem functions correctly under realistic conditions.

### Sensor Bring-Up Tests

Each sensor is verified individually:

- BMP580/BMP585: Bench test confirms ambient pressure readings and verifies that ground reference zeroes correctly.
- BNO086: UART output is verified at 100 Hz to confirm accelerometer, gyroscope, and quaternion fields are populated without dropouts.
- NEO-M9N: Cold-start fix acquisition test is run outdoors to confirm satellite lock and sentence parsing.
- Dual Altimeters: Confirm signals from the primary altimeter and the backup altimeter are correctly registered.

### FSM State Transition Test

With all sensors connected, the FSW is run through a simulated mission on the bench by manually injecting conditions that trigger each state transition. Acceleration is simulated by shaking the unit, and the 600m altitude trigger for AEROBREAK_RELEASE is tested by adjusting the ground reference offset. The transitions are verified by observing the flight_state in received telemetry.

### Telemetry Link Test

The RF link is tested at increasing separation distances. The packet loss rate is estimated by inspecting gaps in the received packet count to confirm adequate link margin for the maximum altitude.

### SD Card Write Verification

A 10-minute continuous run is conducted with the FSW active. The binary log file is converted post-run to verify no missing packets or SD write errors. The SD card is physically removed mid-run to verify that the non-fatal fault path is triggered correctly and telemetry continues uninterrupted.

### Reset Recovery Test

With the FSW running in ASCENT state, the reset button is pressed. The time from reset to first received telemetry packet must be under 5 seconds, the packet counter must resume from its saved value, and the FSM state must recover to ASCENT.

### Payload Deployment Test (Ground Simulation)

A ground-based Payload Deployment Test is performed to validate the ejection mechanism:

1. The model rocket is fully assembled on the test bench with the payload (CAN-7U sized satellite mock) loaded inside the payload bay and secured by the servo-driven spring latch mechanism.
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

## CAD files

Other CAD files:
CANSAT/docs/subsystems/MECHANICAL/cansat+body.f3z

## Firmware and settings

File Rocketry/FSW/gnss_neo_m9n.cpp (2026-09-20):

#include "gnss_neo_m9n.h"
#include <cstring>

// ---- UBX configuration key IDs (u-blox M9 generation, interface description) ----
static constexpr uint32_t CFG_UART1OUTPROT_NMEA   = 0x10740002; // L  (1 byte)
static constexpr uint32_t CFG_MSGOUT_NAV_PVT_UART1 = 0x20910007; // U1 (1 byte)
static constexpr uint32_t CFG_NAVSPG_DYNMODEL     = 0x20110021; // E1 (1 byte), 8 = airborne <4g
static constexpr uint32_t CFG_RATE_MEAS           = 0x30210001; // U2 (2 bytes, ms)

template <typename T>
static inline T rd(const uint8_t* p, size_t off) {
    T v;
    memcpy(&v, p + off, sizeof(T));   // STM32 is little-endian, same as UBX
    return v;
}

// ------------------------------------------------------------------------------
bool GnssNeoM9N::begin(bool configure)
{
    if (configure) {
        const uint8_t nmea_off = 0;
        const uint8_t pvt_on   = 1;
        const uint8_t dyn_air  = 8;                 // airborne <4g
        const uint16_t meas_ms = 100;               // 10 Hz
        const uint8_t rate[2]  = { (uint8_t)(meas_ms & 0xFF), (uint8_t)(meas_ms >> 8) };

        sendValset(CFG_UART1OUTPROT_NMEA,    &nmea_off, 1);
        sendValset(CFG_MSGOUT_NAV_PVT_UART1, &pvt_on,   1);
        sendValset(CFG_NAVSPG_DYNMODEL,      &dyn_air,  1);
        sendValset(CFG_RATE_MEAS,            rate,      2);
    }

    tail_ = 0;
    state_ = ParseState::SYNC1;
    return HAL_UART_Receive_DMA(huart_, rx_buf_, RX_BUF_SIZE) == HAL_OK;
}

// ------------------------------------------------------------------------------
void GnssNeoM9N::poll()
{
    // Restart DMA if a UART error (e.g. overrun) stopped reception
    if (huart_->RxState != HAL_UART_STATE_BUSY_RX) {
        tail_ = 0;
        HAL_UART_Receive_DMA(huart_, rx_buf_, RX_BUF_SIZE);
        return;
    }

    const uint16_t head = RX_BUF_SIZE - __HAL_DMA_GET_COUNTER(huart_->hdmarx);
    while (tail_ != head) {
        feed(rx_buf_[tail_]);
        tail_ = (tail_ + 1) % RX_BUF_SIZE;
    }
}

// ------------------------------------------------------------------------------
bool GnssNeoM9N::getData(GnssData& out)
{
    if (!have_data_) return false;
    out = data_;
    new_data_ = false;
    return true;
}

// ------------------------------------------------------------------------------
// UBX frame parser: B5 62 | class | id | len(LE16) | payload | CK_A CK_B
void GnssNeoM9N::feed(uint8_t b)
{
    switch (state_) {
    case ParseState::SYNC1:
        if (b == 0xB5) state_ = ParseState::SYNC2;
        break;

    case ParseState::SYNC2:
        if (b == 0x62)      state_ = ParseState::CLASS;
        else if (b != 0xB5) state_ = ParseState::SYNC1;
        break;

    case ParseState::CLASS:
        cls_ = b; ck_a_ = 0; ck_b_ = 0;
        ck_a_ += b; ck_b_ += ck_a_;
        state_ = ParseState::ID;
        break;

    case ParseState::ID:
        id_ = b;
        ck_a_ += b; ck_b_ += ck_a_;
        state_ = ParseState::LEN1;
        break;

    case ParseState::LEN1:
        len_ = b;
        ck_a_ += b; ck_b_ += ck_a_;
        state_ = ParseState::LEN2;
        break;

    case ParseState::LEN2:
        len_ |= (uint16_t)b << 8;
        ck_a_ += b; ck_b_ += ck_a_;
        idx_ = 0;
        if (len_ > MAX_PAYLOAD)  state_ = ParseState::SYNC1;   // not something we care about
        else if (len_ == 0)      state_ = ParseState::CK_A;
        else                     state_ = ParseState::PAYLOAD;
        break;

    case ParseState::PAYLOAD:
        payload_[idx_++] = b;
        ck_a_ += b; ck_b_ += ck_a_;
        if (idx_ >= len_) state_ = ParseState::CK_A;
        break;

    case ParseState::CK_A:
        state_ = (b == ck_a_) ? ParseState::CK_B : ParseState::SYNC1;
        break;

    case ParseState::CK_B:
        if (b == ck_b_) handleMessage();
        state_ = ParseState::SYNC1;
        break;
    }
}

// ------------------------------------------------------------------------------
void GnssNeoM9N::handleMessage()
{
    if (cls_ == 0x01 && id_ == 0x07 && len_ == NAV_PVT_LEN) {   // UBX-NAV-PVT
        parseNavPvt(payload_);
    }
    // UBX-ACK-ACK / ACK-NAK (class 0x05) are ignored here
}

// ------------------------------------------------------------------------------
void GnssNeoM9N::parseNavPvt(const uint8_t* p)
{
    data_.year   = rd<uint16_t>(p, 4);
    data_.month  = p[6];
    data_.day    = p[7];
    data_.hour   = p[8];
    data_.minute = p[9];
    data_.second = p[10];
    const uint8_t valid = p[11];
    data_.time_valid = (valid & 0x02) && (valid & 0x04);   // validTime && fullyResolved

    data_.fix_type = p[20];
    data_.fix_ok   = (p[21] & 0x01) != 0;
    data_.num_sats = p[23];

    data_.longitude_deg        = rd<int32_t>(p, 24) * 1e-7;
    data_.latitude_deg         = rd<int32_t>(p, 28) * 1e-7;
    data_.altitude_ellipsoid_m = rd<int32_t>(p, 32) * 1e-3f;
    data_.altitude_msl_m       = rd<int32_t>(p, 36) * 1e-3f;
    data_.h_acc_m              = rd<uint32_t>(p, 40) * 1e-3f;
    data_.v_acc_m              = rd<uint32_t>(p, 44) * 1e-3f;
    data_.vel_down_mps         = rd<int32_t>(p, 56) * 1e-3f;
    data_.ground_speed_mps     = rd<int32_t>(p, 60) * 1e-3f;

    data_.last_update_tick_ms = HAL_GetTick();
    new_data_  = true;
    have_data_ = true;
}

// ------------------------------------------------------------------------------
// UBX-CFG-VALSET (class 0x06, id 0x8A), RAM layer only
bool GnssNeoM9N::sendValset(uint32_t key, const uint8_t* value, uint8_t value_len)
{
    uint8_t frame[32];
    const uint16_t payload_len = 4 + 4 + value_len;   // version,layers,reserved[2] + key + value
    uint16_t n = 0;

    frame[n++] = 0xB5;
    frame[n++] = 0x62;
    frame[n++] = 0x06;
    frame[n++] = 0x8A;
    frame[n++] = payload_len & 0xFF;
    frame[n++] = payload_len >> 8;

    frame[n++] = 0x00;                // version
    frame[n++] = 0x01;                // layers: RAM
    frame[n++] = 0x00;                // reserved
    frame[n++] = 0x00;                // reserved
    frame[n++] = (uint8_t)(key);
    frame[n++] = (uint8_t)(key >> 8);
    frame[n++] = (uint8_t)(key >> 16);
    frame[n++] = (uint8_t)(key >> 24);
    for (uint8_t i = 0; i < value_len; i++) frame[n++] = value[i];

    uint8_t ck_a = 0, ck_b = 0;
    for (uint16_t i = 2; i < n; i++) { ck_a += frame[i]; ck_b += ck_a; }
    frame[n++] = ck_a;
    frame[n++] = ck_b;

    const bool ok = HAL_UART_Transmit(huart_, frame, n, 100) == HAL_OK;
    HAL_Delay(20);
    return ok;
}

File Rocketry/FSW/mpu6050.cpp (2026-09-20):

#include "mpu6050.h"

// Register map
static constexpr uint8_t REG_SMPLRT_DIV   = 0x19;
static constexpr uint8_t REG_CONFIG       = 0x1A;
static constexpr uint8_t REG_GYRO_CONFIG  = 0x1B;
static constexpr uint8_t REG_ACCEL_CONFIG = 0x1C;
static constexpr uint8_t REG_ACCEL_XOUT_H = 0x3B;   // 14 bytes: accel(6) temp(2) gyro(6)
static constexpr uint8_t REG_PWR_MGMT_1   = 0x6B;
static constexpr uint8_t REG_WHO_AM_I     = 0x75;

static constexpr uint32_t I2C_TIMEOUT_MS = 10;

// ------------------------------------------------------------------------------
bool Mpu6050::writeReg(uint8_t reg, uint8_t val)
{
    return HAL_I2C_Mem_Write(hi2c_, addr_, reg, I2C_MEMADD_SIZE_8BIT, &val, 1, I2C_TIMEOUT_MS) == HAL_OK;
}

bool Mpu6050::readRegs(uint8_t reg, uint8_t* buf, uint16_t len)
{
    return HAL_I2C_Mem_Read(hi2c_, addr_, reg, I2C_MEMADD_SIZE_8BIT, buf, len, I2C_TIMEOUT_MS) == HAL_OK;
}

// ------------------------------------------------------------------------------
bool Mpu6050::begin()
{
    uint8_t who = 0;
    if (!readRegs(REG_WHO_AM_I, &who, 1)) return false;
    if (who != 0x68) return false;          // note: some clone boards report 0x70/0x72 - relax this if so

    if (!writeReg(REG_PWR_MGMT_1, 0x80)) return false;   // device reset
    HAL_Delay(100);
    if (!writeReg(REG_PWR_MGMT_1, 0x01)) return false;   // wake, clock = gyro X PLL
    HAL_Delay(10);

    if (!writeReg(REG_CONFIG,       0x03)) return false; // DLPF ~44 Hz accel / 42 Hz gyro, 1 kHz internal rate
    if (!writeReg(REG_SMPLRT_DIV,   9))    return false; // 1000 / (1 + 9) = 100 Hz
    if (!writeReg(REG_GYRO_CONFIG,  0x18)) return false; // +-2000 dps
    if (!writeReg(REG_ACCEL_CONFIG, 0x18)) return false; // +-16 g
    return true;
}

// ------------------------------------------------------------------------------
bool Mpu6050::calibrateGyro(uint16_t samples)
{
    float sum[3] = {0.f, 0.f, 0.f};
    gyro_bias_dps_[0] = gyro_bias_dps_[1] = gyro_bias_dps_[2] = 0.f;

    uint16_t good = 0;
    for (uint16_t i = 0; i < samples; i++) {
        ImuData d;
        if (read(d)) {
            sum[0] += d.gx_dps;
            sum[1] += d.gy_dps;
            sum[2] += d.gz_dps;
            good++;
        }
        HAL_Delay(5);       // matches the 100 Hz output rate roughly
    }
    if (good < samples / 2) return false;

    for (int i = 0; i < 3; i++) gyro_bias_dps_[i] = sum[i] / good;
    return true;
}

// ------------------------------------------------------------------------------
bool Mpu6050::read(ImuData& out)
{
    uint8_t b[14];
    if (!readRegs(REG_ACCEL_XOUT_H, b, 14)) return false;

    auto s16 = [&](int i) -> int16_t { return (int16_t)((b[i] << 8) | b[i + 1]); };

    out.ax_g = s16(0) / ACCEL_LSB_PER_G;
    out.ay_g = s16(2) / ACCEL_LSB_PER_G;
    out.az_g = s16(4) / ACCEL_LSB_PER_G;

    out.die_temp_c = s16(6) / 340.0f + 36.53f;

    out.gx_dps = s16(8)  / GYRO_LSB_PER_DPS - gyro_bias_dps_[0];
    out.gy_dps = s16(10) / GYRO_LSB_PER_DPS - gyro_bias_dps_[1];
    out.gz_dps = s16(12) / GYRO_LSB_PER_DPS - gyro_bias_dps_[2];

    switch (spin_axis_) {
        case SpinAxis::X: out.spin_rate_dps = out.gx_dps; break;
        case SpinAxis::Y: out.spin_rate_dps = out.gy_dps; break;
        default:          out.spin_rate_dps = out.gz_dps; break;
    }

    out.timestamp_ms = HAL_GetTick();
    return true;
}

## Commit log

2026-07-08 CANSAT initial model
    [cansat+body.f3z]
2026-09-27 feat: add driver code for STM32F407VETX and FreeRTOS library source code
2026-10-13 Stage 3: simulated sensors (baro, IMU, GNSS) with fake flight profile
    - shared_state: add IMU and GNSS buffers behind the mutex
    - sim_sensors: deterministic pad/boost/coast/descent/landed model
    - config.h: USE_SIM_SENSORS switch and sim constants
    - main: monitor task prints all buffers at 1 Hz
2026-10-13 Data Layer Added- alpha beta velocity filter, three flags- launch, apogee, impact detection
2026-10-14 Bugs fixed in FSM layer. FSM, rate control, toggle commands, actuatorsstubs done. Made debug console to send telecommands to flight simulator
2026-10-14 Actuators done
2026-10-18 actuators with continuous servo done
2026-10-20 Revert "actuators with continuous servo done"
    This reverts commit 388a0d1f26d877d70a1438b89b27a0625bd216f6.
2026-10-21 Telemetry Stage 1 done
2026-10-24 BNO086 driver implemented. Sensors calibration telecommands done. Battery voltage measurement done.
